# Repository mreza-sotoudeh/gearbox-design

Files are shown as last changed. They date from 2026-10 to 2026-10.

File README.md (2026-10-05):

# Gearbox Design
<p align="center">
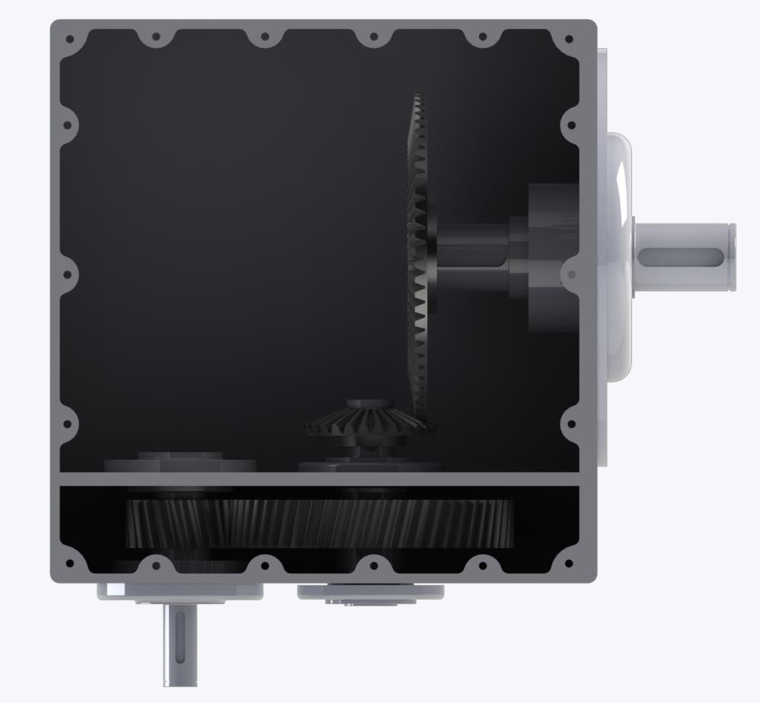
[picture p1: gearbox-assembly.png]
Cutaway view of the gearbox assembly
  
</p>

Mechanical design and analysis of a two-stage reduction gearbox, developed as an academic machine-design project.

The project covers the complete design process from power transmission requirements and gear calculations to shaft design, bearing selection, housing design, and the final SolidWorks assembly.

## Project Overview

The gearbox receives power from an 11 kW motor through a V-belt drive. Speed reduction is achieved using a helical gear stage followed by a bevel gear stage.

| Parameter | Value |
| --- | ---: |
| Motor power | 11 kW |
| Motor speed | 1440 rpm |
| Gearbox input speed  | 500 rpm |
| Helical-stage ratio  | 2.95 |
| Bevel-stage ratio | 2.45 |
| Total internal ratio | Approximately 7.23 |

## Design Scope

* Helical and bevel gear design
* Shaft design and strength calculations
* Bearing selection and arrangement
* Gearbox housing and cover design
* Fastener, seal, and retaining-element selection
* Complete 3D assembly and engineering drawings

## Repository Contents

* [`solidworks/`](solidworks/) — SolidWorks assemblies, parts, drawings, and exported previews
* [`English project report`](docs/gearbox-design-report-en.pdf) — Concise English design report
* [`Persian project report`](docs/gearbox-design-report-fa.pdf) — Complete original project report

## Tools

* SolidWorks
* Engineering design calculations
* Machine-element design methods

## Authors

* Ali Sakhaei
* Mohammadreza Sotoudeh

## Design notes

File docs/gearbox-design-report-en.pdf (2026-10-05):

MACHINE DESIGN II | PORTFOLIO EDITION

# Two-Stage Gearbox Design

### Mechanical analysis, component selection and SolidWorks assembly

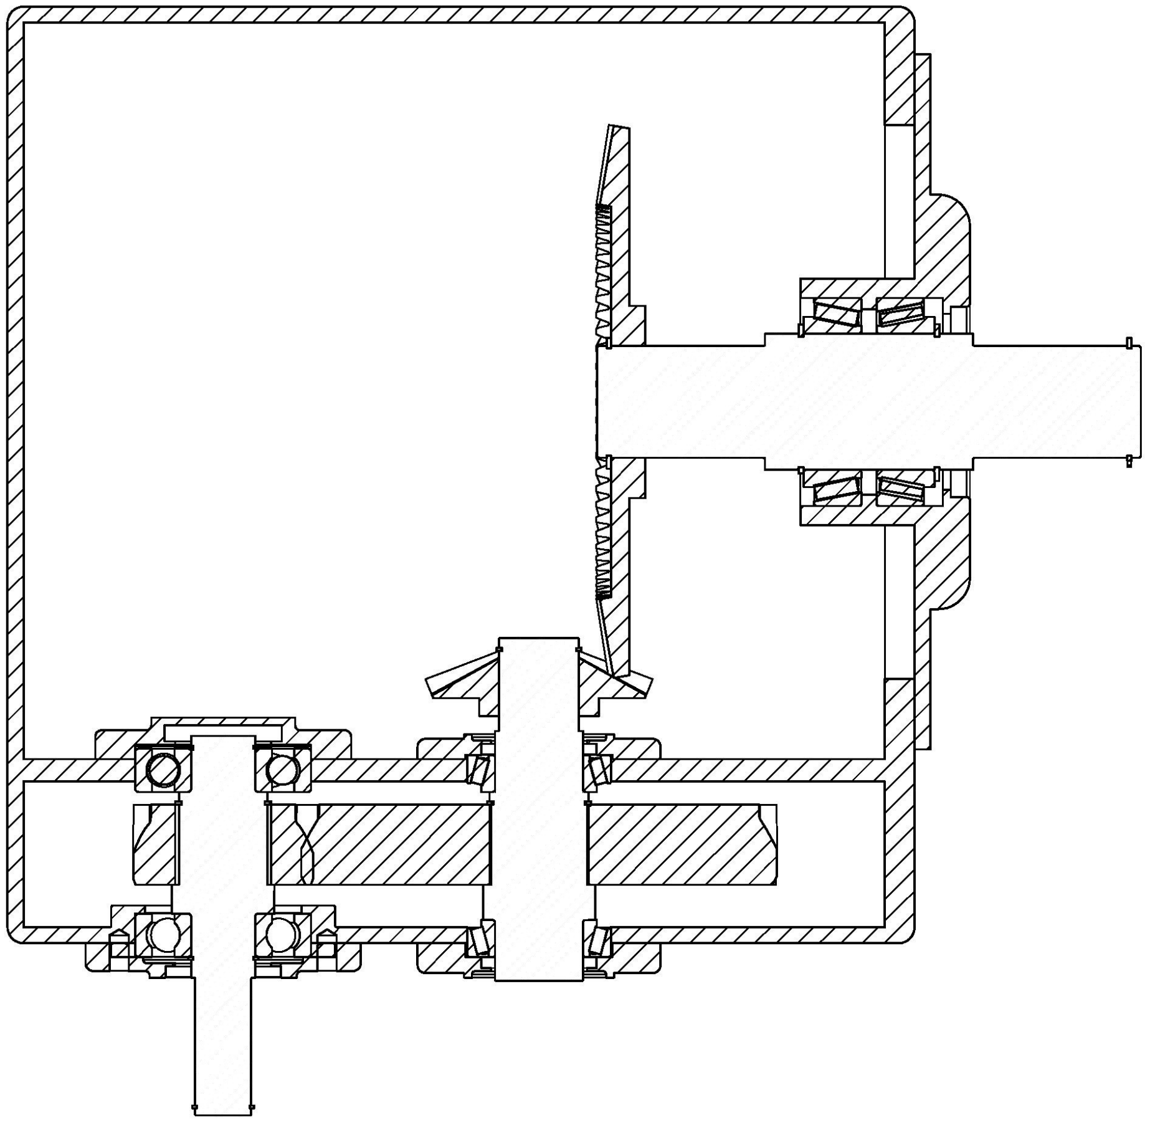
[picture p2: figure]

### Ali Sakhaei | Mohammadreza Sotude

Sharif University of Technology | Academic team project | 2025-2026

github.com/alisakhaei/gearbox-design

01 / PROJECT OVERVIEW

# Design Basis and Transmission Layout

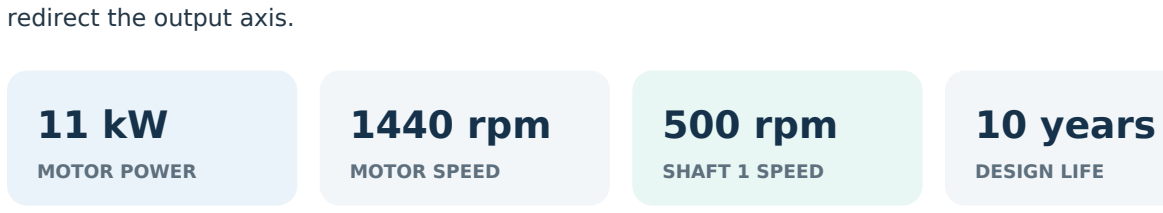
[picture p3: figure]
redirect the output axis.; MOTOR POWER; 1440 rpm; MOTOR SPEED; 500 rpm; SHAFT 1 SPEED; 10 years; DESIGN LIFE
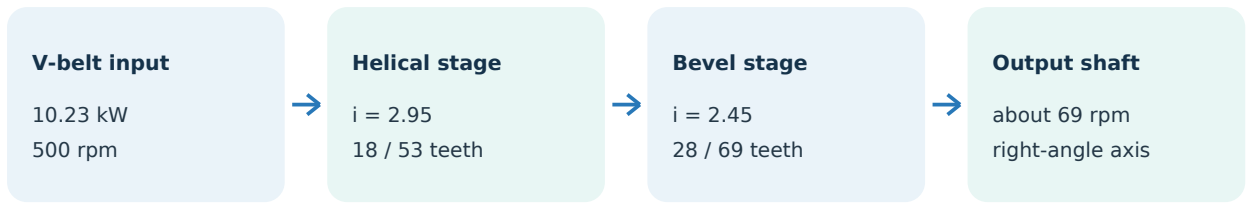
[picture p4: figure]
V-belt input; 500 rpm; Helical stage; 18 / 53 teeth; Bevel stage; 28 / 69 teeth; Output shaft; about 69 rpm; right-angle axis

GEARBOX DESIGN | ACADEMIC PROJECT | 2

The project develops a complete two-stage gearbox from analytical sizing to a detailed SolidWorks assembly. The transmission uses a helical parallel-axis stage followed by a straight bevel stage to

POWER FLOW

CORE ASSUMPTIONS AND CHOICES

Effective power after the V-belt is 10.23 kW, giving 195.4 N m torque at the first gearbox shaft.

Gear material: quenched and tempered 34CrMo4, with design checks based on bending and contact stress.

Shaft material: CK45 steel; stepped diameters were sized under combined bending and torsion.

A 99% reliability target and practical standard sizes were used where specified in the original calculations.

CALCULATION FRAMEWORK

Torque from power and speed | Stage ratio
Tangential tooth load | Basic bearing life

02 / GEAR DESIGN

# Helical and Bevel Gear Stages

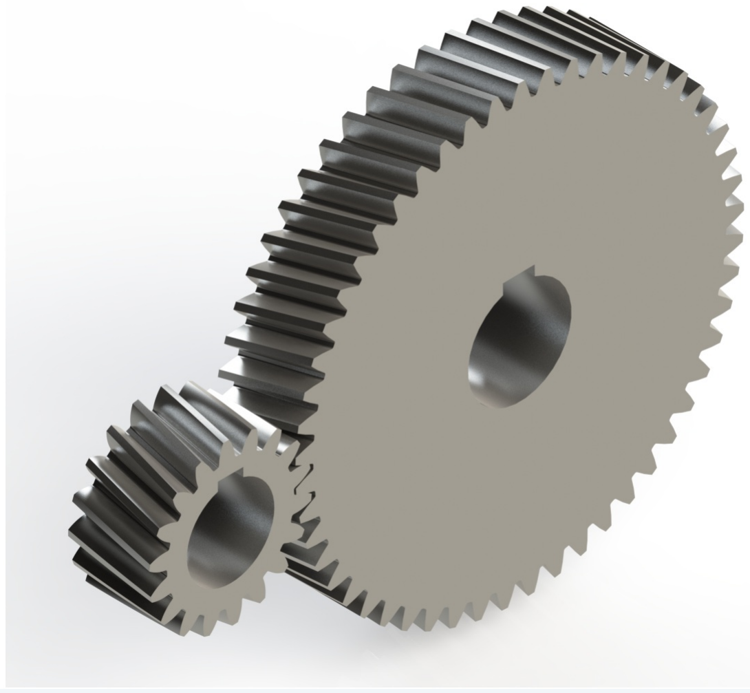
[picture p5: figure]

GEARBOX DESIGN | ACADEMIC PROJECT | 3

STAGE 1 - SELECTED HELICAL PAIR

Parameter | Selected value
Speed ratio | 2.95 : 1
Tooth count | 18 / 53
Normal module | 5 mm
Helix angle | 13 deg
Pitch diameters | 92.4 / 272 mm
Face width | about 51 mm

Both spur and helical alternatives were evaluated. The helical pair was carried forward for the detailed gearbox layout. The selected geometry is based on standard module sizing after bending and surface durability checks.

STAGE 2 - STRAIGHT BEVEL PAIR

Parameter | Selected value
Speed ratio | 2.45 : 1
Tooth count | 28 / 69
Module | 6 mm
Pitch diameters | 168 / 414 mm
Face width | 58 mm
Pitch angles | 22.1 / 67.9 deg

Verified operating point

Power entering stage: 9.92 kW

Shaft speed: about 170 rpm

Transmitted torque: 557.2 N m

# Shaft Design and Bearing Selection

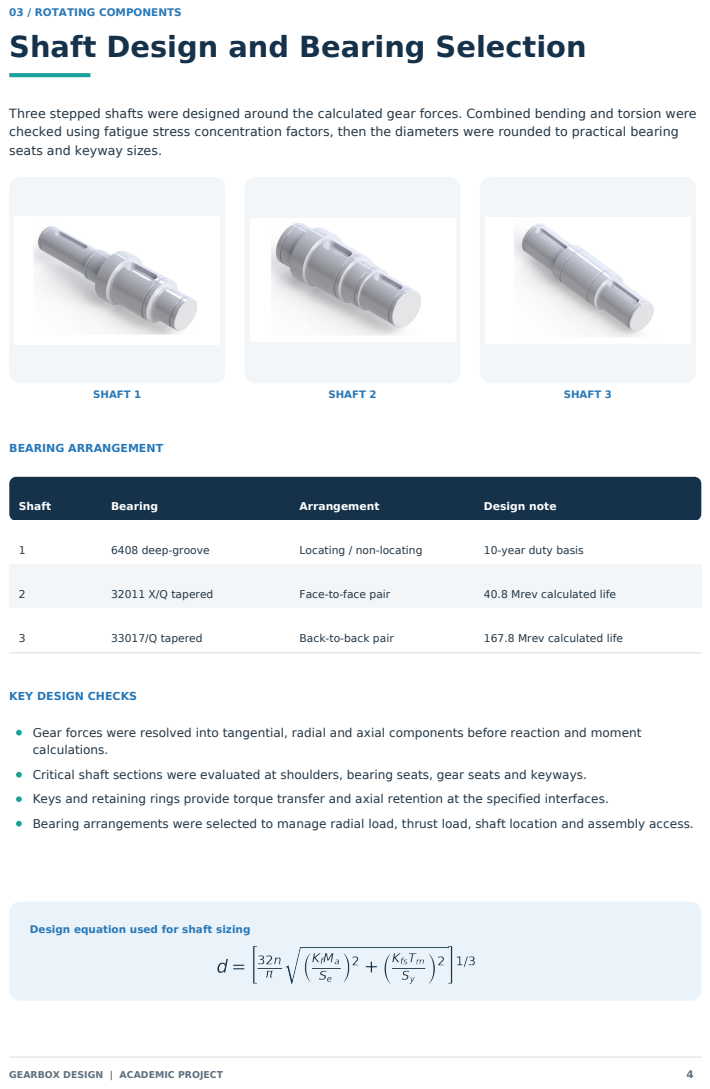
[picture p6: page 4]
03 / ROTATING COMPONENTS; GEARBOX DESIGN | ACADEMIC PROJECT; SHAFT 1; SHAFT 2; SHAFT 3; BEARING ARRANGEMENT; Shaft; Bearing; Arrangement; Design note; 6408 deep-groove; Locating / non-locating; 10-year duty basis; 32011 X/Q tapered; Face-to-face pair; 40.8 Mrev calculated life; 33017/Q tapered; Back-to-back pair; 167.8 Mrev calculated life

Three stepped shafts were designed around the calculated gear forces. Combined bending and torsion were
checked using fatigue stress concentration factors, then the diameters were rounded to practical bearing
seats and keyway sizes.

KEY DESIGN CHECKS

Gear forces were resolved into tangential, radial and axial components before reaction and moment
calculations.

Critical shaft sections were evaluated at shoulders, bearing seats, gear seats and keyways.

Keys and retaining rings provide torque transfer and axial retention at the specified interfaces.

Bearing arrangements were selected to manage radial load, thrust load, shaft location and assembly access.

Design equation used for shaft sizing

04 / ENCLOSURE

# Housing, Fasteners and Sealing

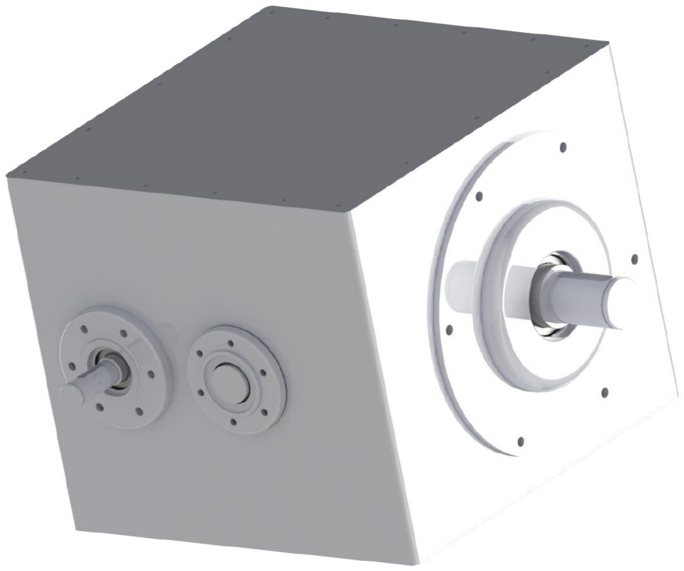
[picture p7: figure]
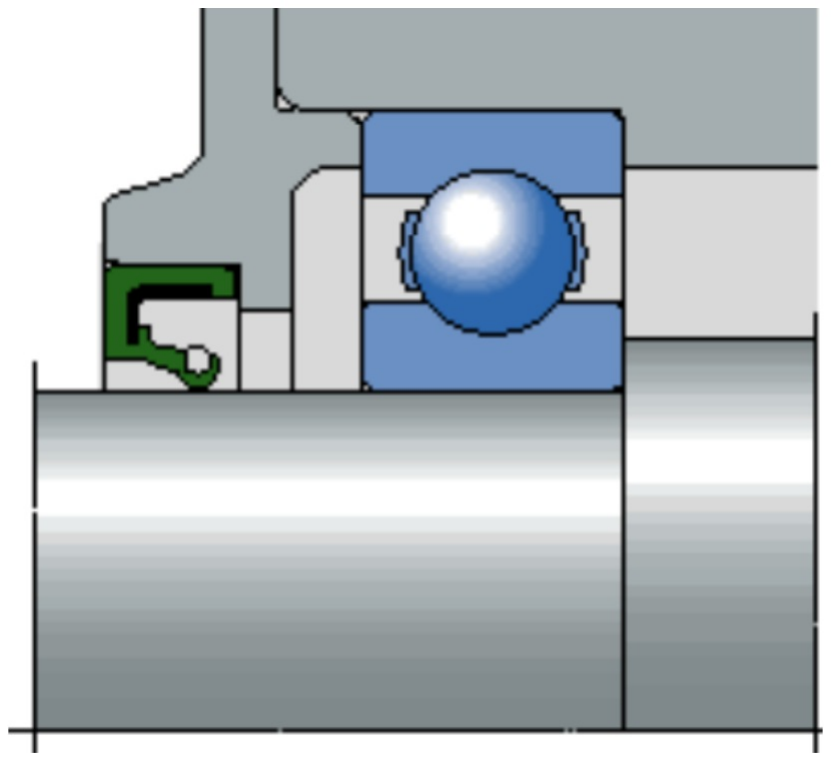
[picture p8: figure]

GEARBOX DESIGN | ACADEMIC PROJECT | 5

HOUSING DESIGN

Steel plate construction was checked against bearing reaction loads.

Calculated local minima were increased to practical 10-12 mm plate selections.

Removable covers, bearing flanges and a dedicated output-shaft housing support assembly and service access.

Fastener sizes include M10, M12, M14 and M16 selections across the casing and support interfaces.

RADIAL SHAFT SEALING

Location | Selected seal
Behind B1 | Type A 40-72-7
Behind B3 | Type A 55-80-8
Behind B6 | Type A 85-120-12

Type A radial lip seals were selected to limit lubricant leakage and contaminant ingress. Seal seats were integrated into the bearing flanges and the third-shaft housing.

Manufacturing intent

Use standard plate thicknesses, standard rolling bearings and catalog seals to keep the design serviceable.

05 / CAD INTEGRATION

# Assembly Architecture and Deliverables

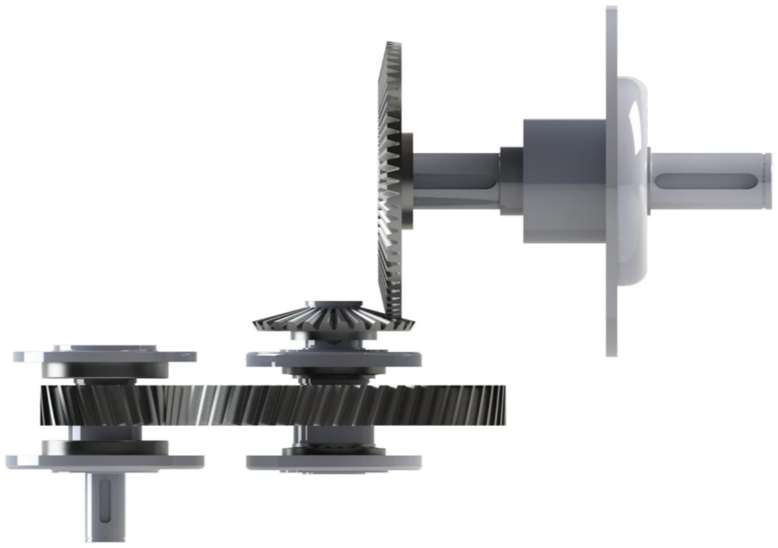
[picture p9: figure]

GEARBOX DESIGN | ACADEMIC PROJECT | 6

ASSEMBLY LOGIC

Shaft 1 carries the helical pinion and is supported by the locating/non-locating ball-bearing pair.

Shaft 2 carries the helical gear and bevel pinion, with a face-to-face tapered-roller arrangement.

Shaft 3 carries the bevel gear and output element, supported by a back-to-back tapered-roller pair.

REPOSITORY-READY DELIVERABLES

Deliverable | Contents
SolidWorks source files | Parts, subassemblies, main assembly and drawings
Engineering drawings | Gears, shafts, flanges, housing and sectional views
Persian calculation report | Complete academic report with detailed calculations
English portfolio report | Concise design summary and selected results

06 / SUMMARY

# Engineering Outcomes

GEARBOX DESIGN | ACADEMIC PROJECT | 7

FINAL CONFIGURATION

Item | Final selection
Architecture | Two-stage, three-shaft, right-angle gearbox
First stage | Helical pair, i = 2.95, module 5 mm
Second stage | Straight bevel pair, i = 2.45, module 6 mm
Internal reduction | Approximately 7.23 : 1
Gear material | 34CrMo4, quenched and tempered
Shaft material | CK45 steel
CAD platform | SolidWorks

WHAT THE PROJECT DEMONSTRATES

Translation of power, speed and service-life requirements into a complete transmission layout.

Gear sizing with bending and surface durability checks, including comparison of spur and helical alternatives.

Integrated design of shafts, bearings, keys, retaining rings, seals, housing plates and fasteners.

CAD assembly planning supported by manufacturing drawings, an exploded view and a bill of materials.

REPORT SCOPE

This English edition is a concise portfolio summary based on the complete Persian calculation report. It preserves the selected dimensions and component choices while omitting student numbers and personal contact details.

PROJECT CREDIT

Academic team project by Ali Sakhaei and Mohammadreza Sotude.

Repository: github.com/alisakhaei/gearbox-design

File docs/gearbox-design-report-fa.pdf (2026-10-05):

دانشگاه صنعتي شريف
دانشكده مهندسي مكانیک

گزارش درس طراحي اجزاء ماشین 2

عنوان

# گزارش پروژه طراحي چرخدندهها و گیربكس

نگارش

## محمدرضا ستوده 402107271 علي سخايي 402107282

دکتر دورعلي

دی 1404

چكيده أ

## گزارش پروژه طراحي چرخدندهها و گیربكس

چكیده

این پروژه به طراحی جامع و تحليل فنی-اقتصاای یايماتن اات اد قد)گ ربيربكبا با تزربر بر بهينهیاز چرخدادهها پيشاای و مخروطی میپریازی. فرایند طراحی ی) یو فاز اصلی تدوین شده ایت؛ ی) فاز اخمت، م ایمها تحليلی ميان چرخدادهها یایه و هليكاد از منظر ااتخاب موای، ظرفيت تحزل باا) و هریناههاا یااااخات صاااو)گ برفات تاا بهيناهترین بریناه ااتخااب و طراحی اهاایی بریی. فااز یو باه طراحی یقيق هندیای و ایات امتی چرخدادهها مخروطی یاایه اختصاای یافته ایات. ی) تزامی مراحل، اصود هنیاز با یيمتن یاتاقانبند و چيدمان شافتها از پيش طراحی شده، مالک عزل قرا) برفته ایات. از وییبیها با)ز این پروژه، ایات الد ی) تصازينبير جهت تعيين ضارایا اطزينان، )و ها یااخت و متریاد بر ایااا ایاتاادا)یها مهندیای ایات. خروجی اهایی شاامل یفترچه محایالاگ بامل، ا شاهها اجرایی، ليمات موای (BOM (و برآو)ی یقيق هرینهها توليد میباشاد به ی) بخش تكزيلی، با بازاگر بر محایلاگ شافت و پویته، به یک طرح جامع از بل یيمتن بيربكب منتهی شده ایت.

فهریت مطالا ب

صفحه | فهرست مطالب

### 1 مقدمه1 |

### 2 تشريح مسئله 2 |

2.1 محایلاگ م دماتی مزان پيچشی3 |

### 3 چرخدنده ی ساده 4 |

3.1 )اد)بير چرخداده یایه | 6

### 4 چرخدنده ی هلیكال 7 |

4.1 )اد)بير چرخداده هليكاد 9 |

### 5 چرخدنده ی هلیكال يا ساده؟10 |

### 6 چرخدنده ی مخروطي ساده 11 |

6.1 )اد)بير چرخداده مخروطی یایه 14 |

### 7 شافت | 1 15

7.1 محایلاگ اوليه شافت 1 15 |
7.2 محایله قطر شافت 1 | 16
7.3 محایله خا) شافت 17 | 1
7.4 ااتخاب بيرینگ برا شافت 1 18 |
7.5 ازا بلی شافت 1 20 |

### 8 شافت | 2 21

8.1 محایلاگ اوليه شافت 2 21 |
8.2 محایله قطر شافت 2 22 |
8.3 محایله خا) شافت 22 | 2
8.4 ااتخاب بيرینگ برا شافت 2 23 |
8.5 ازا بلی شافت 2 24 |

### 9 شافت 25 | 3

9.1 محایلاگ اوليه شافت 3 و قطر25 |
9.2 محایلاگ خا) شافت | 3 26
9.3 ااتخاب بيرینگ برا شافت 3 | 26

فهریت مطالا ب

9.4 ازا بلی شافت 3 27 |
10.1 محایله ضخامت و)ق و Housing28 |
10.2 محایله پيچ ها پویته 29 |
10.3 )اد)بير بيربكب 30 |
10.3.1 خا)ج بيربكب 30 |
10.3.2 یاخل بيربكب 31 |
10.3.3 یاخل بيربكب ربدون پویتها32 |

### 11 نشتبندی 33 |

12.1چرخداده یایهPinion 34 |
12.2چرخداده یایه Gear 35 |
12.4چرخداده هليكاد Gear 37 |
12.5چرخداده مخروطی Pinion 38 |
12.6 چرخداده مخروطی Gear39 |
12.7شافت 1 40 |
41 | Flange 1 (For B1)12.8
42 | Flange 2 (For B2) 12.9
12.10 شافت 2 43 |
44 | Flanges 3&4 (For B3 & B4) 12.11
12.12 شافت 3 45 |
12.14 پویته بي ربكب (Case(47 |
12.15 ی) پویته ب يربكب رDoor Caseا 48 |
12.16 ا شه م طع بيربكب 49 |
50 | Exploded View 12.17
51 | Bill of Material 12.18

### 13 مونتاژ 52 |

فهریت مطالا ب

13.1 احوه مواتاژ 52 |
13.2 تثليت محو) و یو)اای قطعاگ53 |

فصل اود: م دمه 1

## 1 مقدمه

یايماتنها اات اد قد)گ و ی) )أا آنها بيربكبها، ا شای حياتی ی) ماشاينآالگ صانعتی ایفا میبنند . طراحی یک بيربكب با)آمد، تنها به محایالاگ ترو)یک محدوی ازیشاوی، بلكه مماتلر اتخا تصازيزاگ مهندیای ی) زمينه ااتخاب موای، )و ها یااخت و بهينهیااز اقتصاای ایات. ی) این پروژه، هدف اصااالی طراحی اجرا یادهبناد یاک یااايماااتن اات ااد قد)گ با تكيه بر آموختهها پيشاااين و ایتاادا)یها طراحی اجرا ایت. )واد طراحی ی) این برا) با بر)یاای تطلي ی ميان چرخدادهها پيشاااای ریااایها و هليكاد آغاز میبریی. از آاجاایی باه ااتخااب بين این یو اوع چرخادااده ممااات يزااً بر باازیهی، ميران ا)تعااشااااگ و هرینهها ماشاينبا) تأثيربذا) ایات، ی) فاز اخمات پروژه، این یو )اهكا) از منظر متریاد و هرینهها تولياد مو)ی وابااو قرا) برفتاهاااد. ی) بخش یو ، طراحی چرخاداادههاا مخروطی برا اات ااد توان بين محو)ها مت اطع مد اظر قرا) برفته ایت. این برا) عالوه بر ا)ائه محایالاگ یقيق، به جنلهها اجرایی از جزله ا شاهها یااخت و برآو)ی ليمت موای رBOMا اير میپریازی تا یک پكيج بامل مهندی ی از ایده تا توليد )ا ا)ائه یهد .

فصل یو : تشریح ممرله 2

## 2 تشريح مسئله

هزااطو) به ی) بالا توضايح یایه شاد، ی) این پروژه ميخواهين چرخداده ها بيربكب پروژه 2
)ا طراحی بنين. برا مرحله اود )اه حلها یااایه و هليكاد )ا از اظر موای و هرینه یاااخت م ایمااه و چرخداده منایاا )ا ااتخاب و بطو) بامل طراحی ازایيد. برا مرحله یو چرخداده ها مخروطی یاایه اياز خواهد بوی به ی) اینجا هن )اه حل )ا تا طراحی بامل پيش بلرید . شاااكل اهایی یاده ها باید با ااچه ی) پروژه 2 از اظر بيرینگ بند و اصااا طراحی ازویید تا حد امكان هزماااز یاشااته باشااد. بماايا) خوشاحالن به ی) این پروژه با توجه به آموخته هایتان ميتواايد از اظر ضاریا اطزينان، ااتخاب موای، )و یاخت و )و اصا تزامی تصزيزها )ا خویتان بگيرید .خروجی این پروژه محایلاگ و ا شه ها یاخت و هرینه یاخت چرخداده ها ميلاشد . با توچه به اینكه ی) پروژه ها 2 و 3 محایلاگ شافت ها و بيرینگ ها و بداه و اشات بند ها )ا ااجا یایه اید، با توجه به ارییكی ابعای با فرضاياگ اوليه ی) صاو)تيكه تزایل به ا)ایه طرح بامل بيربكب یاشااته باشاايد، با توجه به ابعای یاده ها طراحی شااده، ميتواايد محایاالاگ مربوطه )ا بطو) خالصاااه با اقتلاا از پروژه ،2 تكرا) ازویه و طرح بامل بيربكب و ا شاااه ها اجرایی قطعااگ ان، ليمااات موای و قطعااگ و هریناه تولياد اارا اير تكزيال بریه و تحویال یهياد. ااجاا این بخش تاا 30٪ ازره اضافی برا بروه شزا خواهد یاشت.

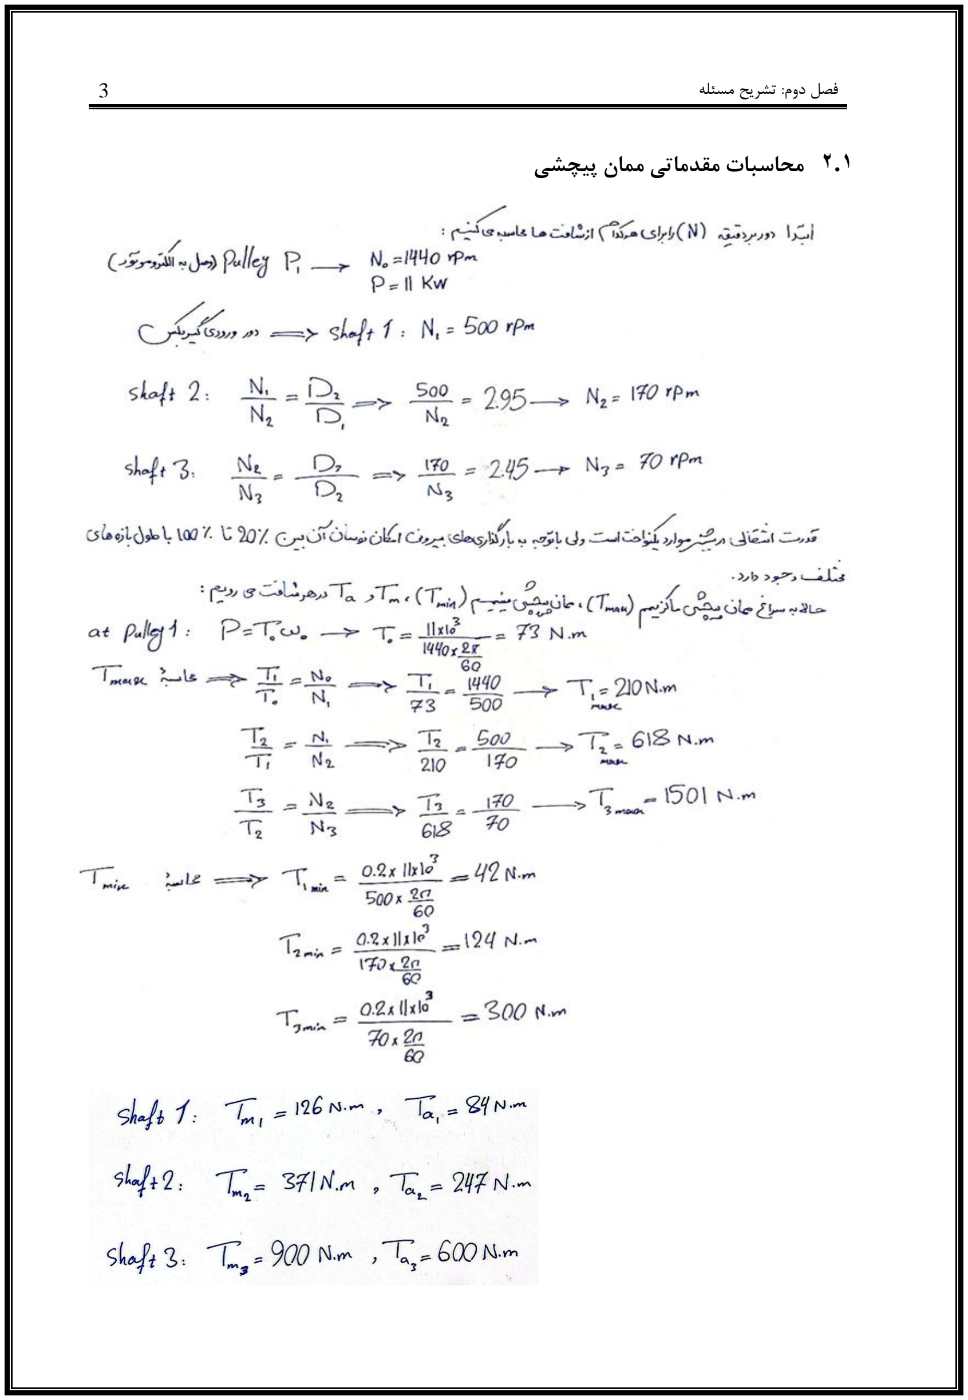
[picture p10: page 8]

فصل یو : تشریح ممرله 3

محاسبات مقدماتي ممان پیچشي

2

1

فصل یو : چرخداده یایه 4

## چرخدندهی ساده

3

فصل یو : چرخداده یایه 5

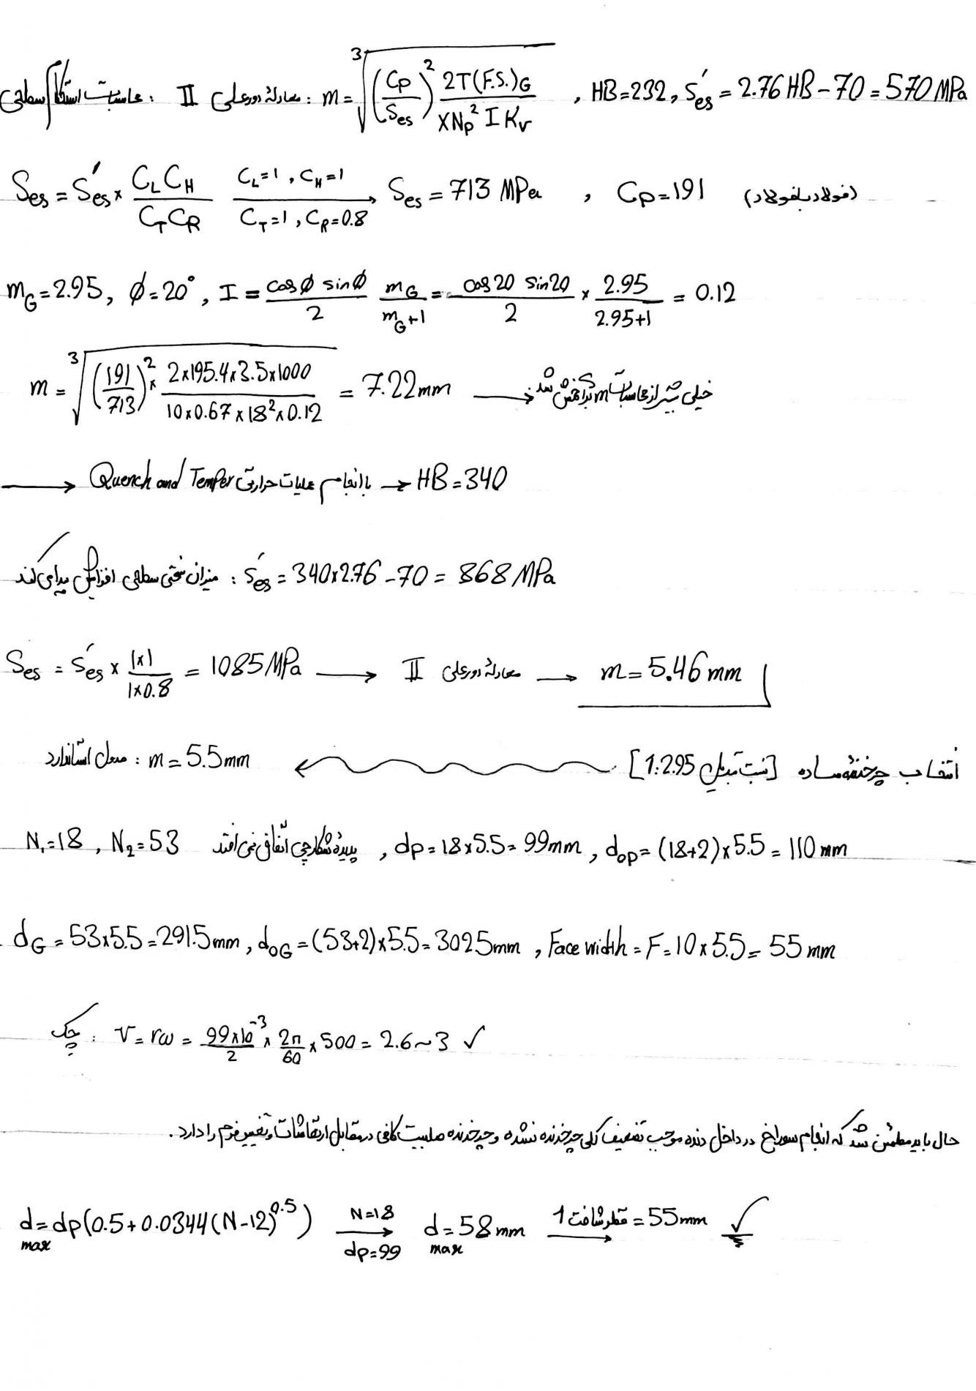
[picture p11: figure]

فصل یو : چرخداده یایه 6

رندرگیری چرخدنده ی ساده

3

1

فصل چها) : چرخداده هليكاد 7

## چرخدندهی هلیكال

4

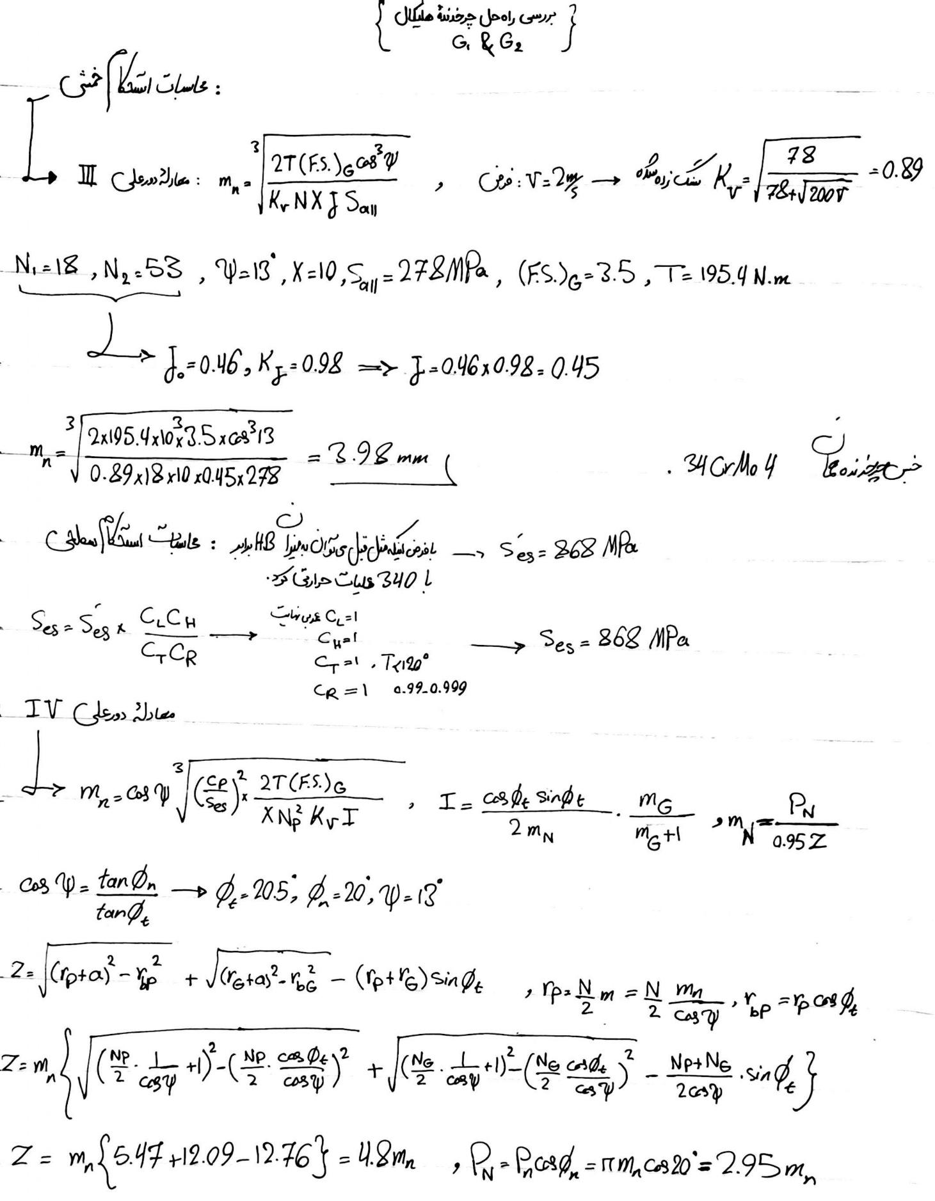
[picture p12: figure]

فصل چها) : چرخداده هليكاد 8

فصل چها) : چرخداده هليكاد 9

رندرگیری چرخدنده ی هلیكال

4

1

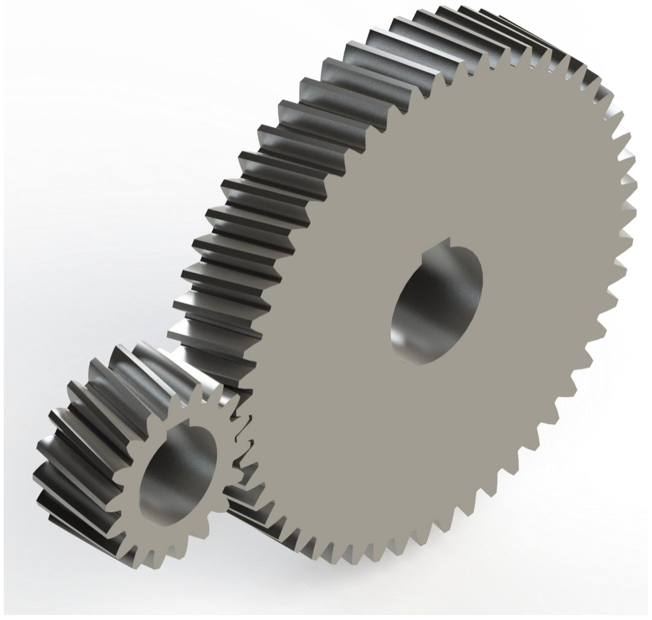
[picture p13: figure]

فصل پنجن: ااتخاب بين یو اوع چرخداده 10

## 5 چرخدندهی هلیكال يا ساده؟

هر یو اوع چرخادااده باه ییااات آماده، وییبیهاا الز برا بيربكب )ا یا)ااد. از لحااظ هریناه یااخت و مایه، ااتخاب چرخداده هليكاد م رون به صارفهتر ایات. به عالوه، چرخدادهها هليكاد به یليل قطر خا)جی بزترشاان امالت به چرخدادهها یاایه، فضاا بزتر )ا از بيربكب میبيراد. اللته یااخت چرخد اده هليكاد به یليل عزلياگ حرا)تی و یانگ زین یاختتر و بزی پرهرینه تر ایات؛ اما فوالی بزتر ی) آن ایتفایه شده ایت.

بنابراین از چرخداده اوع هليكاد ایتفایه میبنين.

فصل ششن: چرخداده مخروطی یایه 11

## 6 چرخدندهی مخروطي ساده

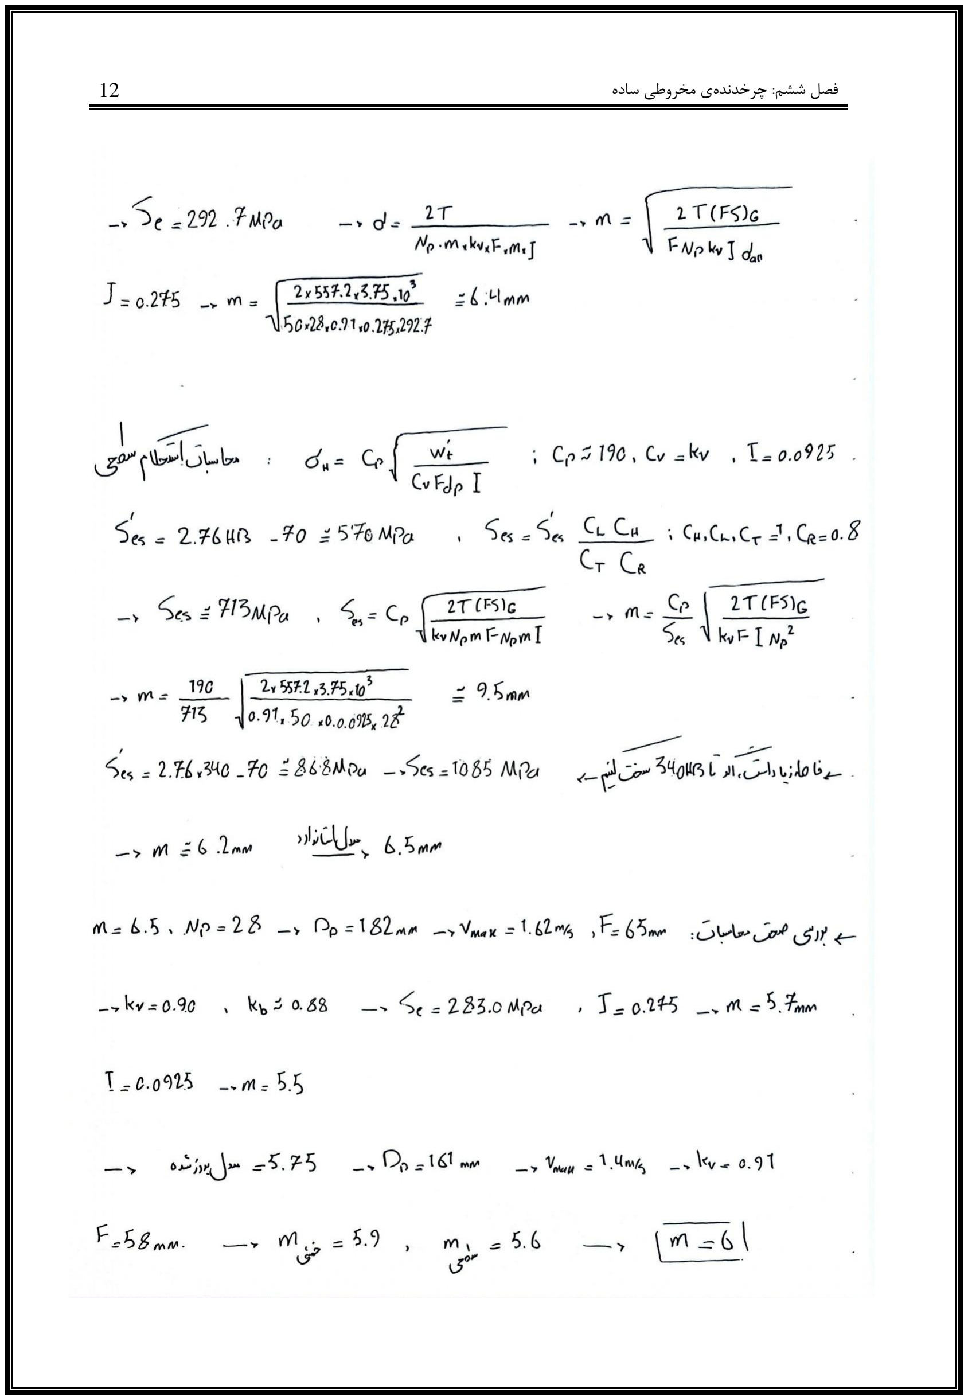
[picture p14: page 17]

فصل ششن: چرخداده مخروطی یایه 12

فصل ششن: چرخداده مخروطی یایه 13

فصل ششن: چرخداده مخروطی یایه 14

### 6.1 رندرگیری چرخدنده مخروطي ساده

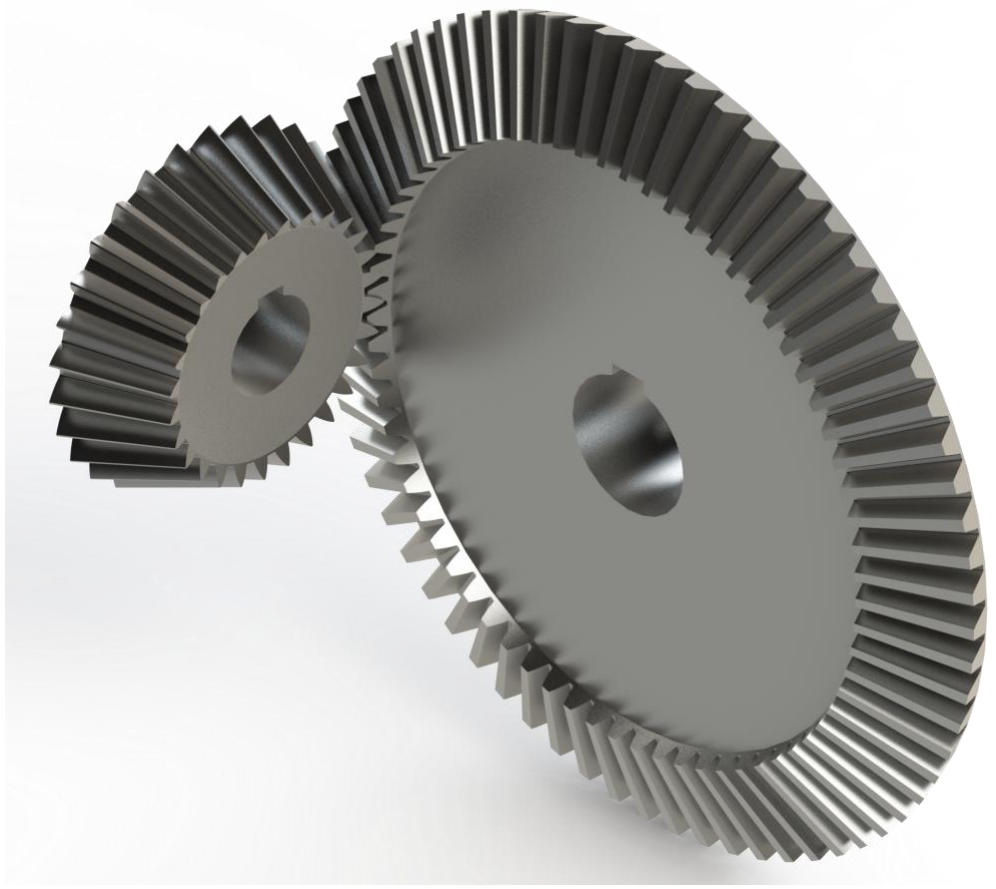
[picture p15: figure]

فصل هفتن: شافت 1 15

## 7 شافت 1

### 7.1 محاسبات اولیه شافت 1

این شااافت اماالت به پروژه قلل تغيير چنداای اكریه ایاات چون قطر با چرخداده هليكاد 1 ی) هزان حدوی برا پروژه 3 به ییت آمد.

16

فصل هفتن: شافت 1

محاسبه قطر شافت 1

7

2

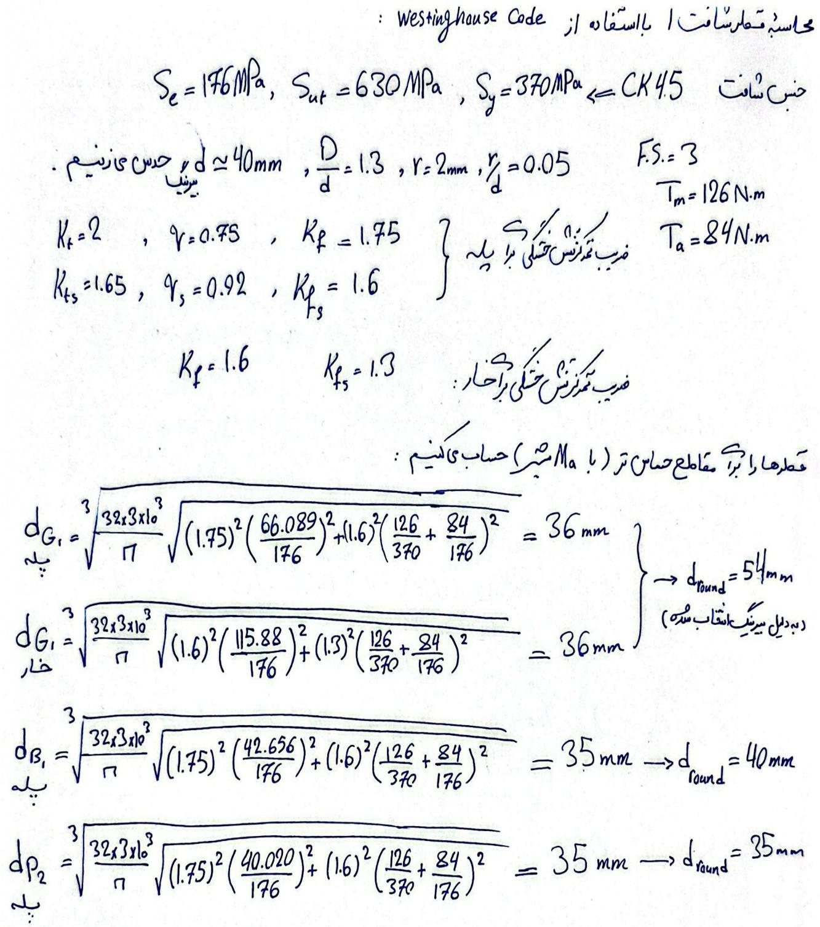
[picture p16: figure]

17

فصل هفتن: شافت 1

محاسبه خار شافت 1

7

3

18

فصل هفتن: شافت 1

انتخاب بیرينگ برای شافت 1

7

4

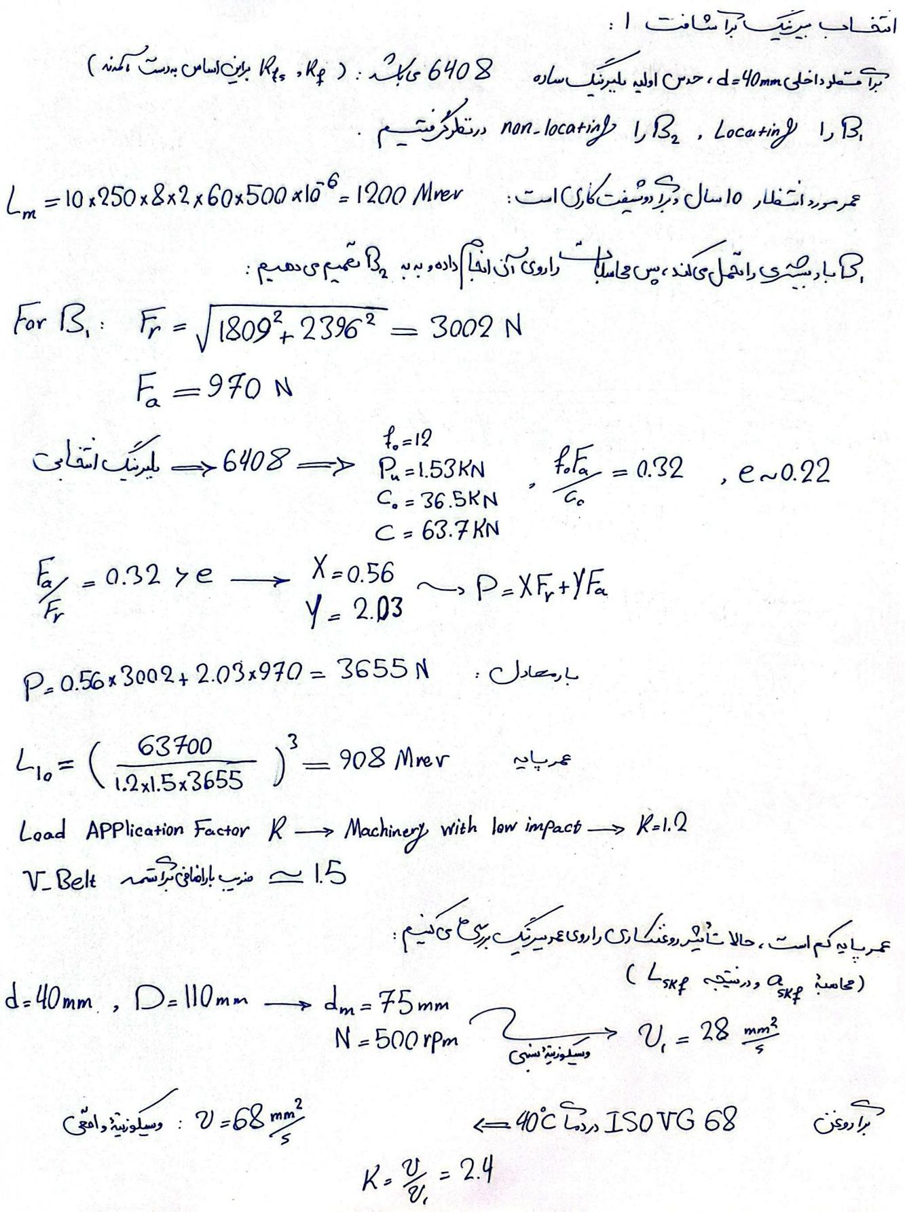
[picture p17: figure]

فصل هفتن: شافت 1 19

20

فصل هفتن: شافت 1

نمای کلي شافت 1

7

5

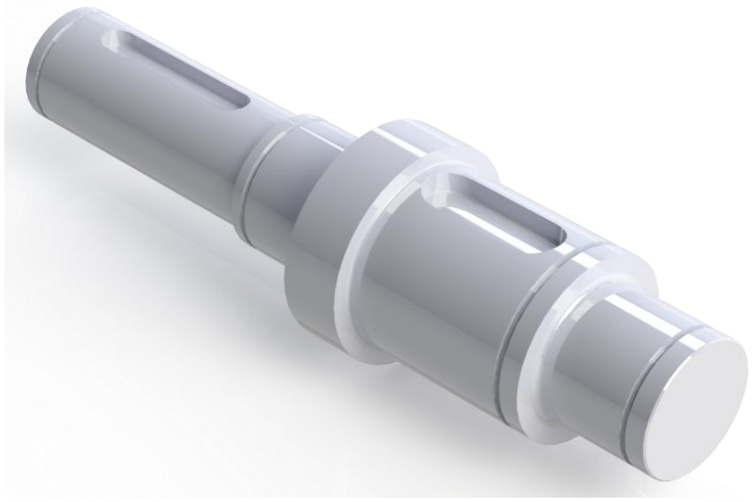
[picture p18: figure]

21

8 شافت 2 | فصل هشتن: شافت 2

محاسبات اولیه شافت 2

8

1

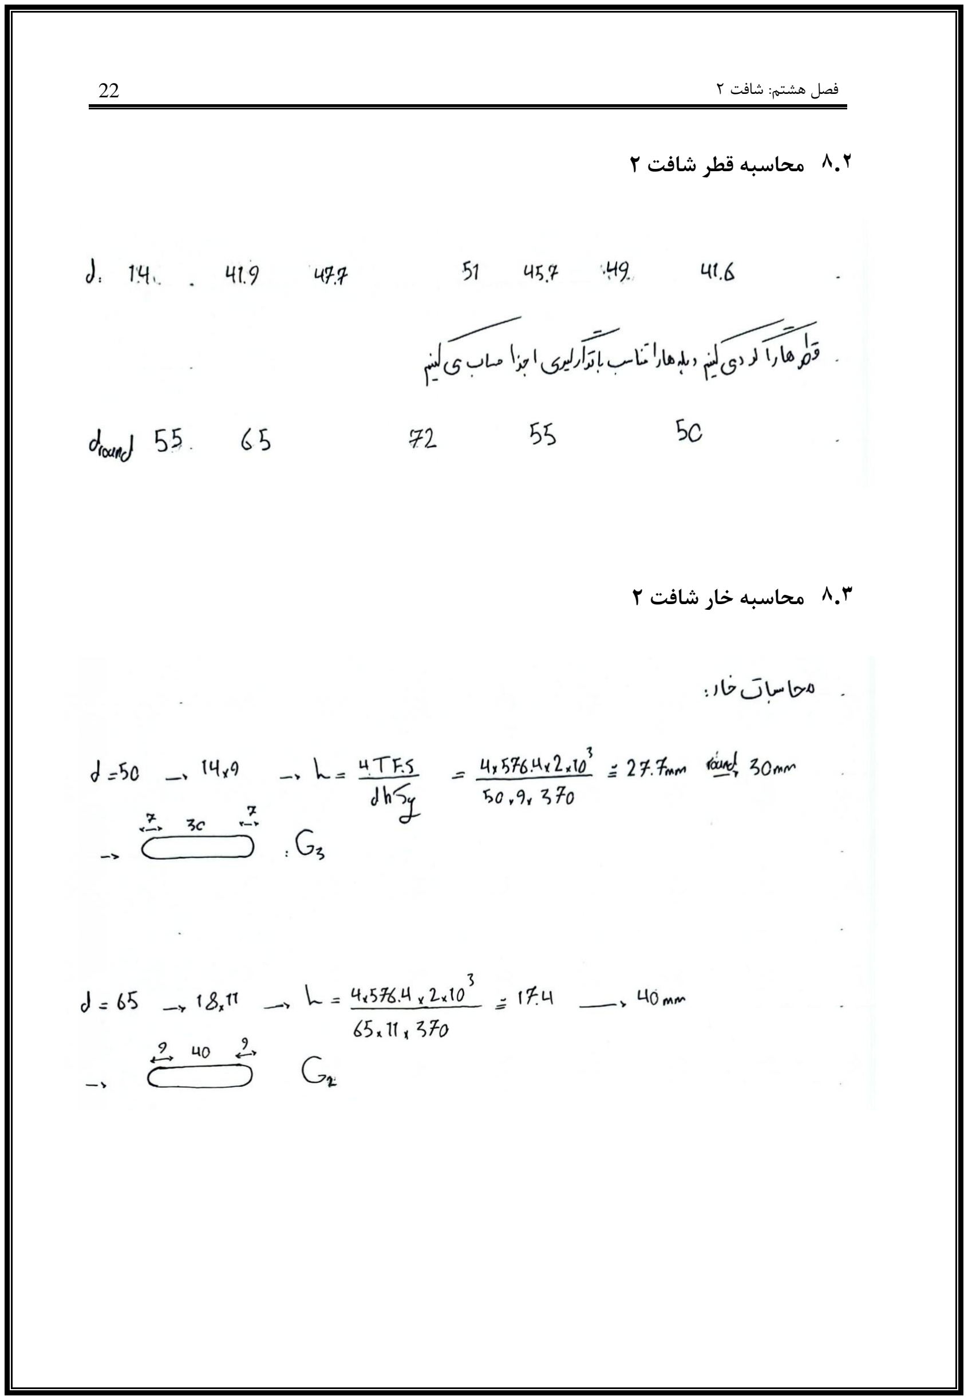
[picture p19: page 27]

فصل هشتن: شافت 2 22

### 8.2 محاسبه قطر شافت 2

### 8.3 محاسبه خار شافت 2

23

فصل هشتن: شافت 2

انتخاب بیرينگ برای شافت 2

8

4

24

فصل هشتن: شافت 2

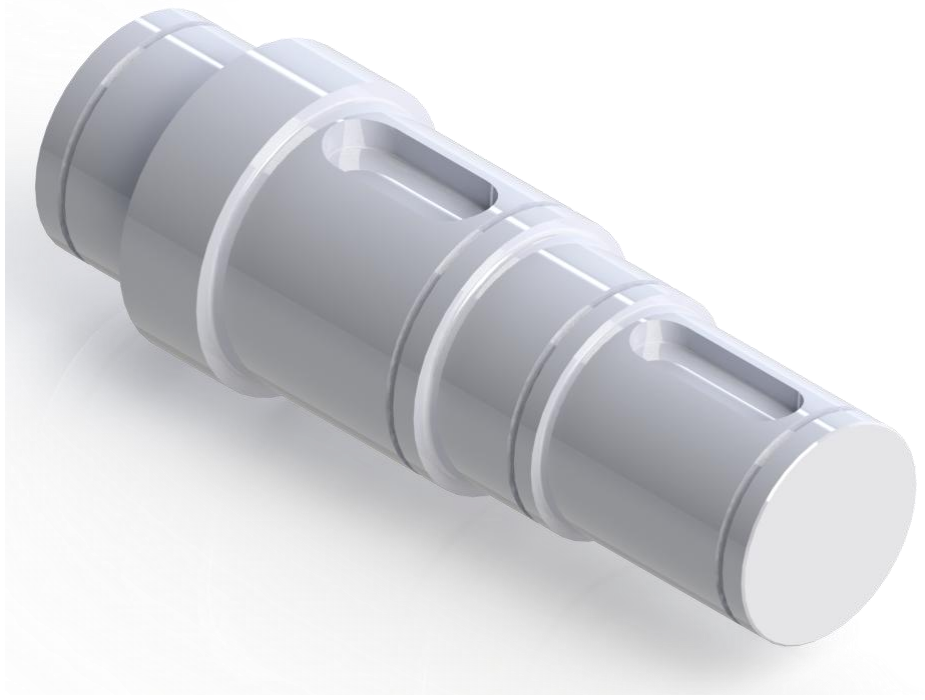
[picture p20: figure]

نمای کلي شافت 2

8

5

فصل اهن: شافت 3 25

## 9 شافت 3

### 9.1 محاسبات اولیه شافت 3 و قطر

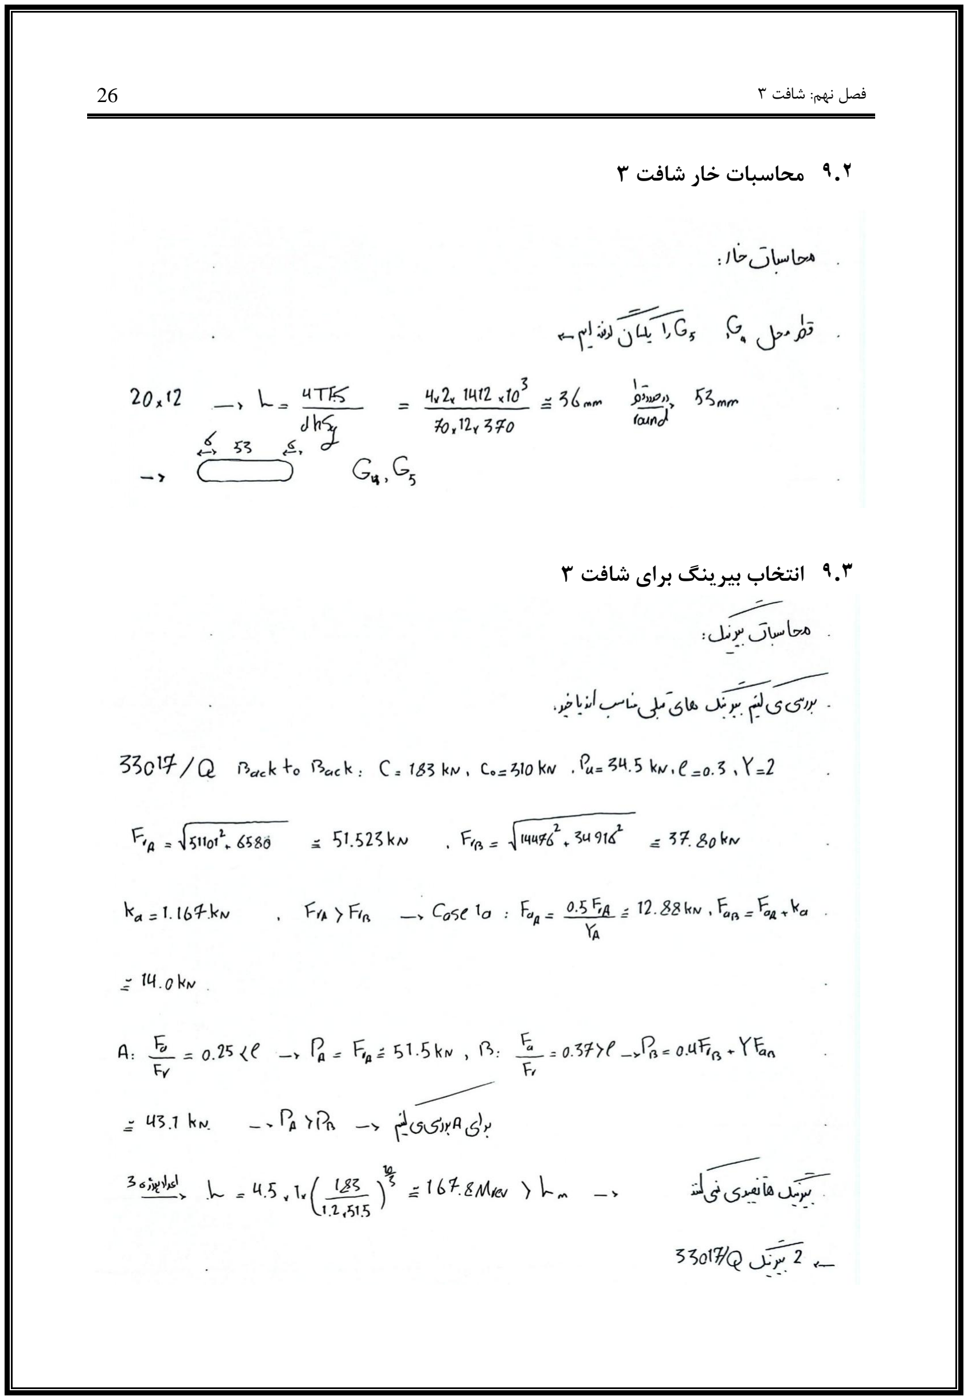
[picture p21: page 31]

فصل اهن: شافت 3 26

### 9.2 محاسبات خار شافت 3

### 9.3 انتخاب بیرينگ برای شافت 3

27

فصل اهن: شافت 3

نمای کلي شافت 3

9

4

فصل یهن: پویته بيربكب 28

## 10 پوستهی گیربكس

10.1محاسبه ضخامت ورق و Housing

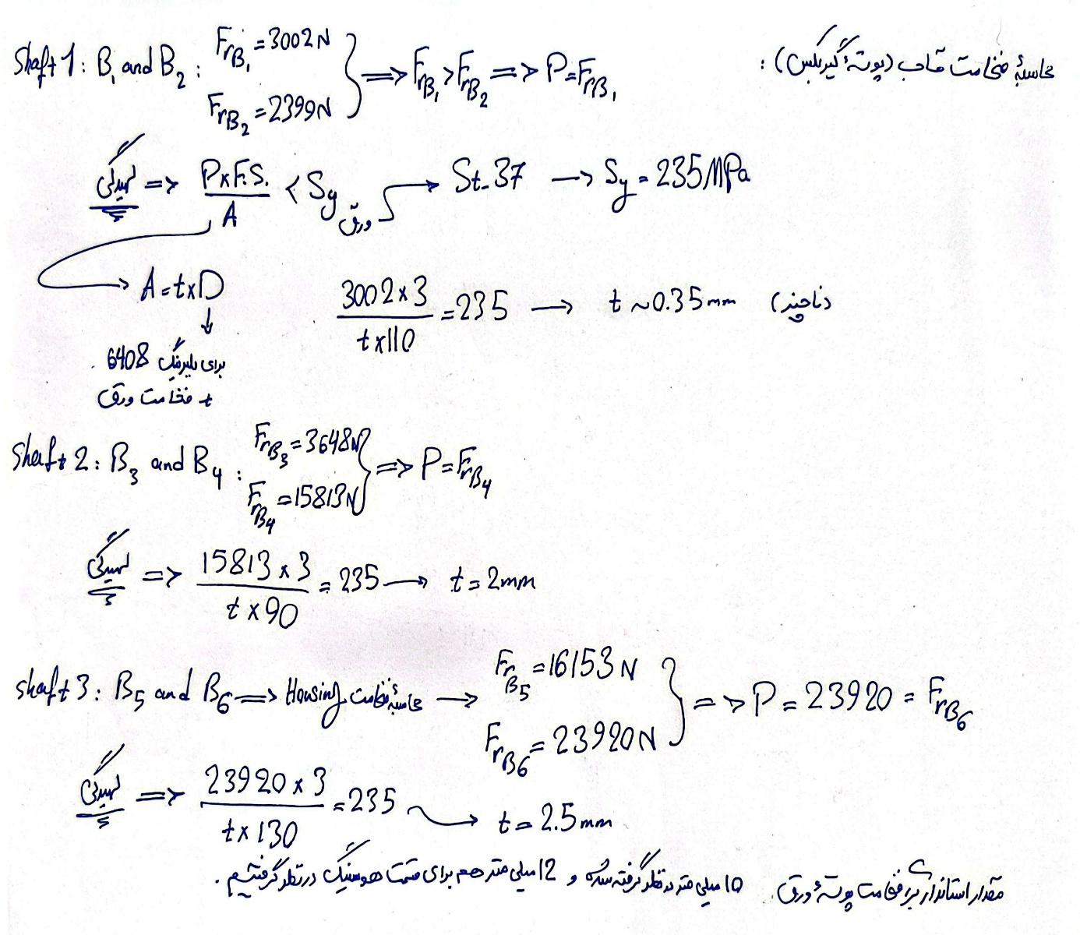
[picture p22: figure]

فصل یهن: پویته بيربكب 29

10محاسبه پیچ های پوسته

2

فصل یهن: پویته بيربكب 30

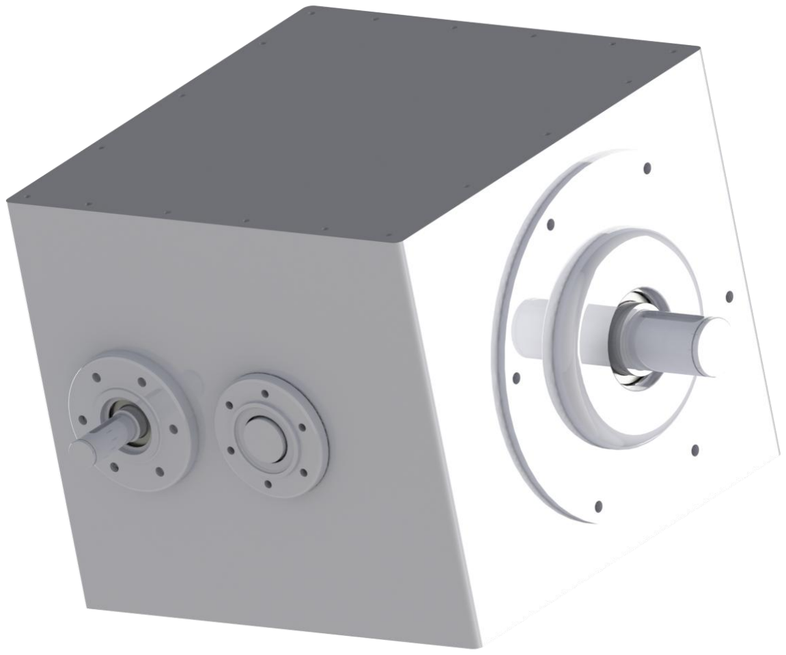
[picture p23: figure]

10رندرگیری گیربكس

3

10خارج گیربكس

3

1

فصل یهن: پویته بيربكب 31

10داخل گیربكس

3

2
توضااايحااگ: ااافیهاا 3G و 4G باایاد تاا پلاه مجاو)شاان امتدای پيدا بنند به ی) ار افرا) این با) برا چرخدادهها مخروطی یاااليدو)بب م دو) الوی.

فصل یهن: پویته بيربكب 32

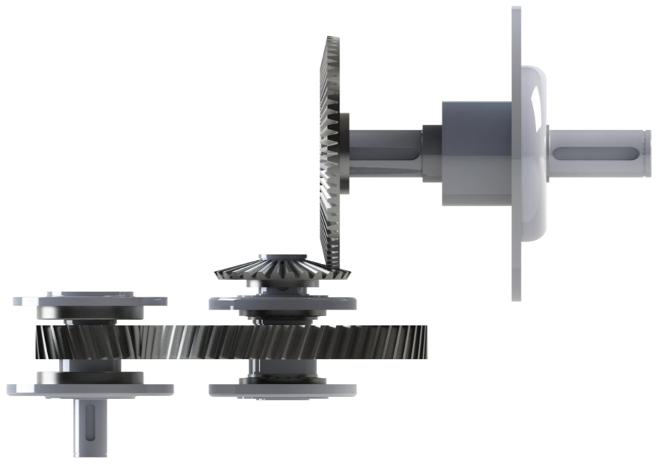
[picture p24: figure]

10داخل گیربكس )بدون پوسته(

3

3

فصل یازیهن: اشتبند 33

## 11 نشتبندی

ی) این بخش به ااتخاب اشاتبند برا جلوبير از و)وی بریوغلا) و خروج )وغن از بيربكب میپریازین. هزانطو) به مشاخ ایات، باید با توجه به قطر آن قمازت از شاافت به بيرینگها 1B، 3B و 5B قرا) یا)اد، بایاهازد منایاا ااتخاب شاوی. الز به بر ایات به برا بيربكب ها معزوال ی) صانعت از بایاه ازد اوع A ایتفایه میشوی. ااتخاب بایه ازد ها از قرا) زیر ایت:
- یک عدی بایه ازد 40-72-7 TypeA برا پشت 1B
- یک عدی بایه ازد 55-80-8 TypeA برا پشت 3B
- یک عدی بایه ازد 85-120-12 TypeA برا پشت 6B )و فلنج ها و هویاينگ شاافت ،3 محل اصاا برا این بایاه ازدها ی) اظربرفته شادهایات. احوه اصا هن باید به صو)گ زیر باشد:

فصل یوازیهن: ا شهها اجرا 34

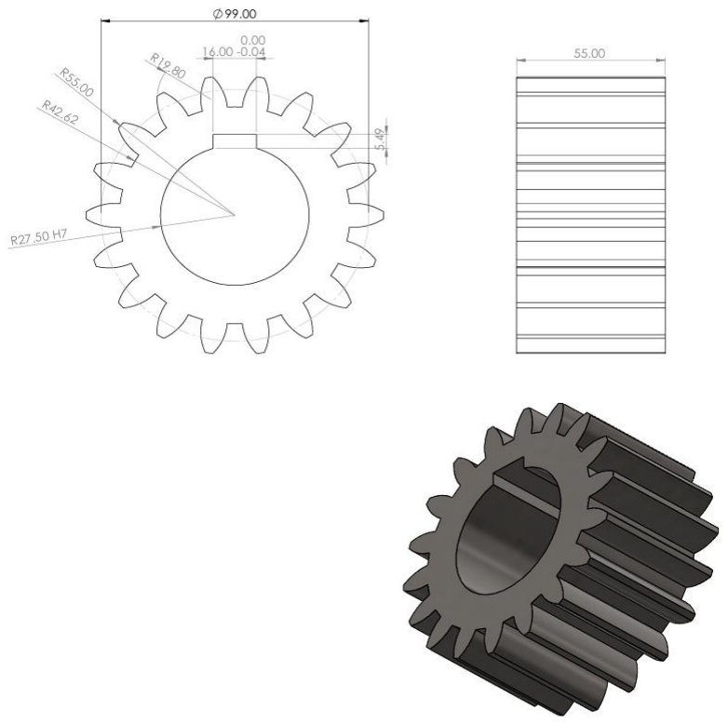
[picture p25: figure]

## 12 نقشهها

### 12 چرخدنده ی ساده Pinion

1

فصل یوازیهن: ا شهها اجرا 35

12چرخدنده ی ساده Gear

2

فصل یوازیهن: ا شهها اجرا 36


### 12 چرخدنده ی هلیكال Pinion

3

فصل یوازیهن: ا شهها اجرا 37

12چرخدنده ی هلیكال Gear

4

فصل یوازیهن: ا شهها اجرا 38


12چرخدنده ی مخروطي Pinion

5

فصل یوازیهن: ا شهها اجرا 39

12چرخدنده ی مخروطي Gear

6

12.7شافت 1 | فصل یوازیهن: ا شهها اجرا 40


فصل یوازیهن: ا شهها اجرا 41

Flange 1 (For B1)12

8

فصل یوازیهن: ا شهها اجرا 42


Flange 2 (For B2)12

9

12.10شافت 2 | فصل یوازیهن: ا شهها اجرا 43

فصل یوازیهن: ا شهها اجرا 44


Flange

s

3&4 (For B3 & B4

)12

.11

12.12شافت 3 | فصل یوازیهن: ا شهها اجرا 45

فصل یوازیهن: ا شهها اجرا 46

12.13هوسینگ برای رولربیرينگهای شافت 3 (Housing(


فصل یوازیهن: ا شهها اجرا 47

12پوسته گیربكس (Case(

.14

12.15 در پوسته گیربكس )Door Case ) | فصل یوازیهن: ا شهها اجرا 48


فصل یوازیهن: ا شهها اجرا 49

### 12 نقشه مقطع گیربكس

.16

فصل یوازیهن: ا شهها اجرا 50


Exploded View 12

.17

فصل هشتن: ا شهها اجرا 51

Bill of Material 12.18

Column1 | Column2
1 Shaft 1
2 Shaft 2
3 Shaft 3
4 Case
5 Case Door
6 Helical Gear Mo.5 D.92.4 7 Helical Gear Mo.5 D.272
8 Straight Bevel Gears Mo.6 D.168 9 Straight Bevel Gears Mo.6 D.414 10 Deep Grove Ball Bearing 6408 11 Tapper Roller Bearing 32011X/Q 12 Tapper Roller Bearing 330177/Q 13 Flange 1 (Bearing 1)
14 Flange 2 (Bearing 2)
15 Flange 3 (Bearing 3)
16 Flange 4 (Bearing 4)
17 Housing (5, 6)
18 6*M14*2 Screw Machine
19 6*M16*2 Screw Machine
20 6*M12*1.75 Screw Machine 21 6*M12*1.75 Screw Machine 22 6*M16*2 Screw Machine
23 18*M10*1.5 Screw Machine 24 Circlip DIN 471 - 35*1.5 25 Circlip DIN 471 - 40*1.75 26 Circlip DIN 471 - 55*2
27 Circlip DIN 472 - 62*2
28 Circlip DIN 472 - 50*2
29 Circlip DIN 471 - 85*3
30 Circlip DIN 471 - 70*2.5

فصل یيریهن: مواتاژ 52

## 13 مونتاژ

13.1نحوه مونتاژ

اجرایی به باید مواتاژ شواد علا)تند از: پویته بيربكب، ی) بيربكب، شافت،1 شافت،2 شافت،3 پولی،2 چرخداده هليكاد،1 چرخداده هليكاد ،2 چرخداده مخروطی،3 چرخداده مخروطی،4 چرخ زاجير، یو عدی بللرینگ ،6408 یو عدی )ولربيرینگ 32011 Face-to-Face، یو عدی )ولربيرینگ 33017 به صو)گ Back -to-Back، فلنجها 1و2و 3و،4 یه عدی بایه ازد، هاویينگ، پيچ ها، خا) و خا) فنر ها. ابتدا 1B( ا )و شافت1 اصا می بنين و شافت )ا ی) پویته بيربكب قرا) می یهين، یپب 2B
)ا از یزت ییگر شافت، )و آن اصا می بنين. خا) 1G( ا )و شافت قرا) یایه و بعد از آن، چرخداده )و شافت یوا) می شوی. خا) فنر ها )ا از یوطرف وا)ی می بنين تا پشت بللرینگ ها )ا بگيراد. بعد، فلنجها 1و2 )ا ی) محل مشخ شده )و پویته پيچ میبنين. حاال 2P( ا اير اصا می بنين.

ی) این مرحله به یراغ شافت 2 )فته و ابتدا 3B( ا از یزت چپ )و شافت اصا می بنين.
یپب، 4B از یزت ییگر پشت پله اصا می شوی. با بعد از اصا خا)، اتصاد چرخدادههایت به برا اینبا) اود 2G ی) محل مربوطه اصا و بعد فلنج مربوط به 4B از یزت )ایت اصا میشوی. حاال 4G )ا از یزت )ایت ی) محل مربوطه بين جا خا)فنر و پله قرا) می یهين. خا)فنر ها )ا ی) جا خوی قرا) یایه و یپب فلنج 3B( ا از یزت چپ ی) پویته پيچ می بنين.

قلل از اصا شافت3 )و پویته بيربكب، ابتدا یو )ولربرینگ 5و 6 از یوطرف )و شافت3 قرا)
یایه می شواد. یپب 4G بعد از قرا)بير خا) مربوطه، اصا می شوی. یو)اخ ایجای شده )و پویته ی) این قمزت بزی از قطر 4G بر)بتر ایت تا خوایته یواد برآو)یه شوی رتا یاده 4G بتوااد از بشویبی بيربكب بيرون بيایدا. حاال هاویينگ )و )ولربيرینگ ها اصا شده و بل مجزوعه وا)ی پویته می شوی. بعد از آن، هاویينگ به پویته پيچ شده و خا)فنر ها و 5G( و شافت3 اصا می شواد. ی) آخر هن بعد از اصا ی) پویته، بایه ازد ها تهيه شده )و فلنج ها 1 و 3 و بيرون هاویينگ
قرا) می بيراد.

فصل یيریهن: مواتاژ 53

13.2تثبیت محوری و دوراني قطعات

شافت 1

تثليت ها یو)اای:
2P: با ایتفایه از یک خا) ممتطيلی mm8 × mm10 به طود 55 ميلی متر تثليت یو)اای می شوی. 1G: با ایتفایه از یک خا) ممتطيلی mm10 × mm16 به طود 44 ميلی متر تثليت یو)اای می شوی.

تثليت ها محو) :
2P: پشت آن تویط خا)فنر 35 DSH مها) شده و جلو آن هن پله قرا) یا)ی. 1G: ی) پشت آن پله و ی) جلو آن خا)فنر 54 DSH قرا) یایه شده ایت. 1B: ی) شافت 1 یو بللرینگ یایه ایتفایه شده به 1B( ا Locating ی) اظربرفتين. بنابراین، بنب یاخلی آن از جلو با پله و از پشت با خا)فنر 40 DSH تثليت محو) شدهایت. به عالوه، بنب خا)جی آن هن از پشت با فلنج و از جلو با مااعی به ی) پویته بيربكب طراحی شده، مها) شده ایت. 2B: این بللرینگ به صو)گ locating-Non طراحی شده، به این حالت به بنب یاخلی از جلو با خا)فنر 40 DSH و از پشت با پله مها) شده و بنب خا)جی آن از یوطرف آزای ایت.

شافت 2

تثليت ها یو)اای:
2G: با ایتفایه از یک خا) ممتطيلی mm11 × mm18 به طود 43 ميلی متر تثليت یو)اای می شوی. 3G: با ایتفایه از یک خا) ممتطيلی mm9 × mm14 به طود 44 ميلی متر تثليت یو)اای می شوی.

تثليت ها محو) :
2G: پشت آن تویط خا)فنر 62 DSH مها) شده و جلو آن هن پله قرا) یا)ی. 3G: ی) پشت آن پله و ی) جلو آن خا)فنر 50 DSH قرا) یایه شده ایت.

فصل یيریهن: مواتاژ 54

4B & 3B: ی) شافت ،2 یو عدی )ولربرینگ مخروطی به صو)گ Face-to-Face ایتفایه شده ایت. پشت بنب خا)جی 3B و جلو بنب خا)جی 4B با فلنج ها مربوطه مها) شداد. به عالوه، جلو بنب یاخلی 3B و پشت بنب یاخلی 4B با پله ها مجاو)شان امكان حربت محو) ادا)اد.

شافت 3

تثليت ها یو)اای:
4G: با ایتفایه از یک خا) ممتطيلی mm12 × mm20 به طود 90 ميلی متر تثليت یو)اای می شوی.

5G: با ایتفایه از یک خا) ممتطيلی mm12 × mm20 به طود 90 ميلی متر تثليت یو)اای می شوی.

تثليت ها محو) :
4G: پشت آن تویط خا)فنر 70 DSH مها) شده و جلو آن هن پله قرا) یا)ی به 4G با ایتفایه از اافی متصل شده به آن، به پله می )ید . 5G: ی) پشت آن پله و ی) جلو آن خا)فنر 70 DSH قرا) یایه شده ایت.

6B & 5B: ی) شافت ،3 یو عدی )ولربرینگ مخروطی به صو)گ Back-to-Back ایتفایه شده ایت. جلو بنب خا)جی 5B و پشت بنب خا)جی 6B با فلنج ها مربوطه مها) شداد. به عالوه، ی) پشت بنب یاخلی 5B و جلو بنب یاخلی 6B با ایتفایه از خا)فنر ها 85 DSH امكان حربت محو) ادا)اد.

فصل چها)یهن: برآو)ی قيزت 55

## 14 برآورد قیمت

الز به بر ایت به به یليل قطعی اینترات ی) ) وز ها پنجشنله، جزعه و شنله امكان تكزيل این قمزت وجوی اداشت. اما ليمت قطعاگ ی) صفح ه 51 موجوی ایت.

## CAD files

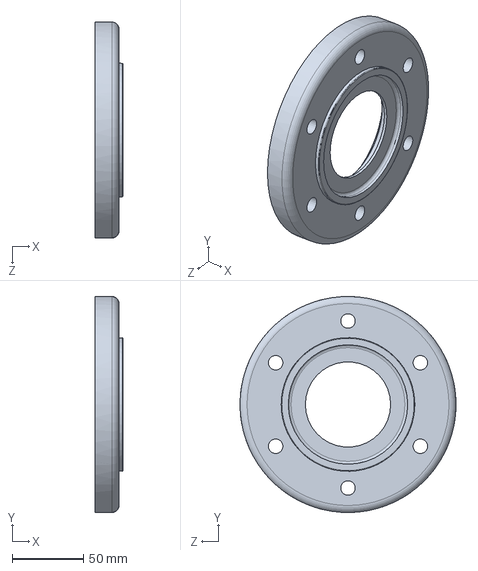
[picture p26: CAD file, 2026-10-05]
solidworks/Flange 3.SLDPRT
19.9 x 152.0 x 152.0 mm

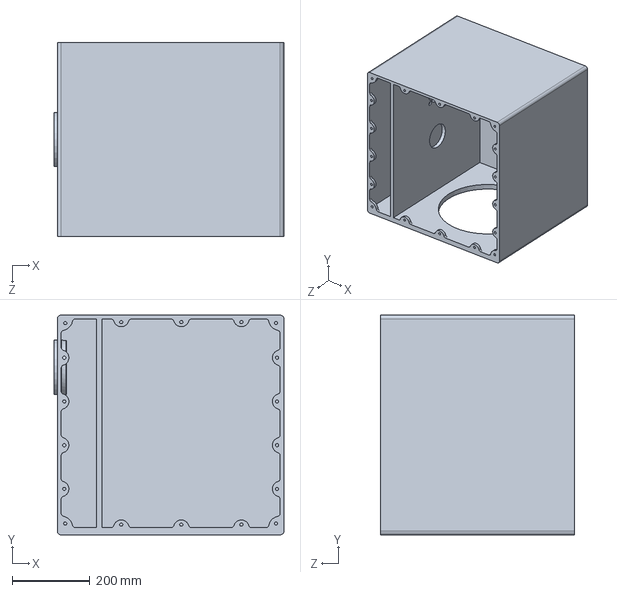
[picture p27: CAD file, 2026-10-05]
solidworks/Part2.SLDPRT
593.5 x 567.2 x 500.0 mm

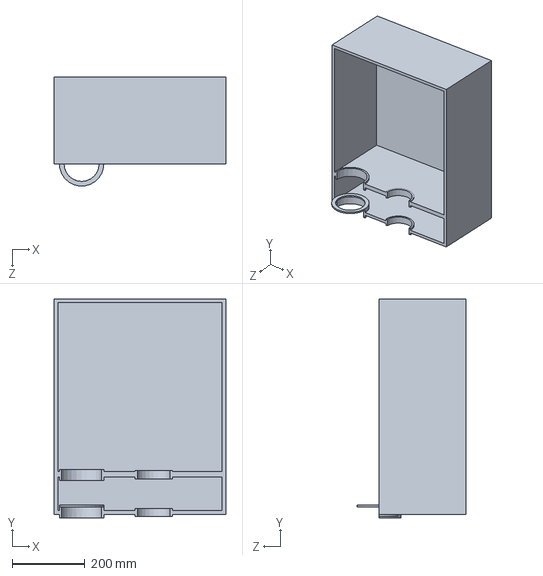
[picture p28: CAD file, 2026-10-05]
solidworks/Case.SLDPRT
470.0 x 600.0 x 298.5 mm

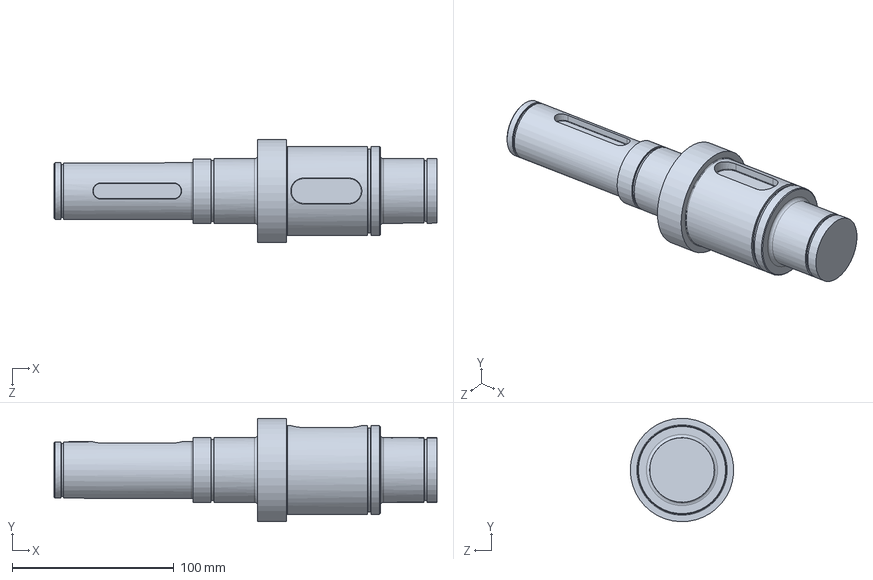
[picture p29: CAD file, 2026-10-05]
solidworks/Shaft1.SLDPRT
237.0 x 64.0 x 64.0 mm

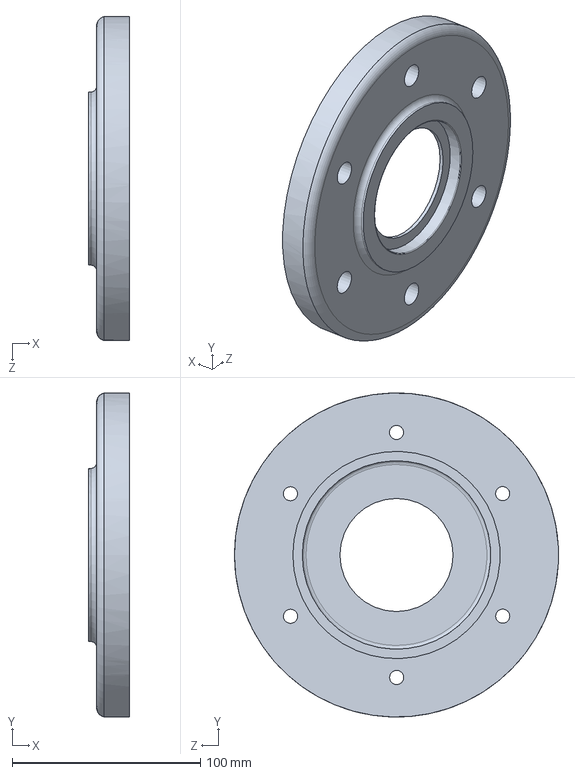
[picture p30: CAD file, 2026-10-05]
solidworks/Flange 1.SLDPRT
21.5 x 172.0 x 172.0 mm

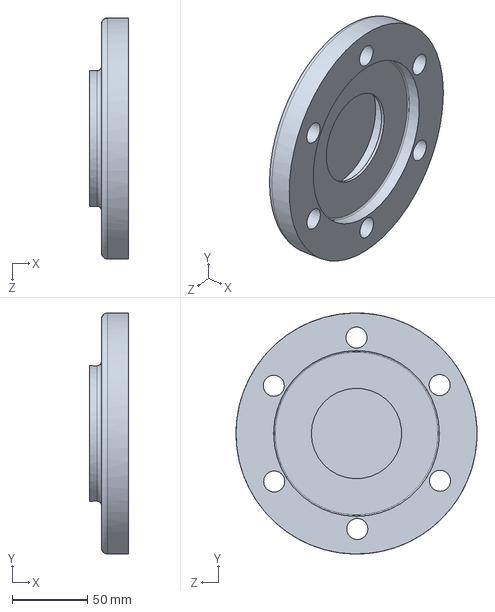
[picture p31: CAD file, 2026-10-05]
solidworks/Flange 2.SLDPRT
25.9 x 160.0 x 160.0 mm

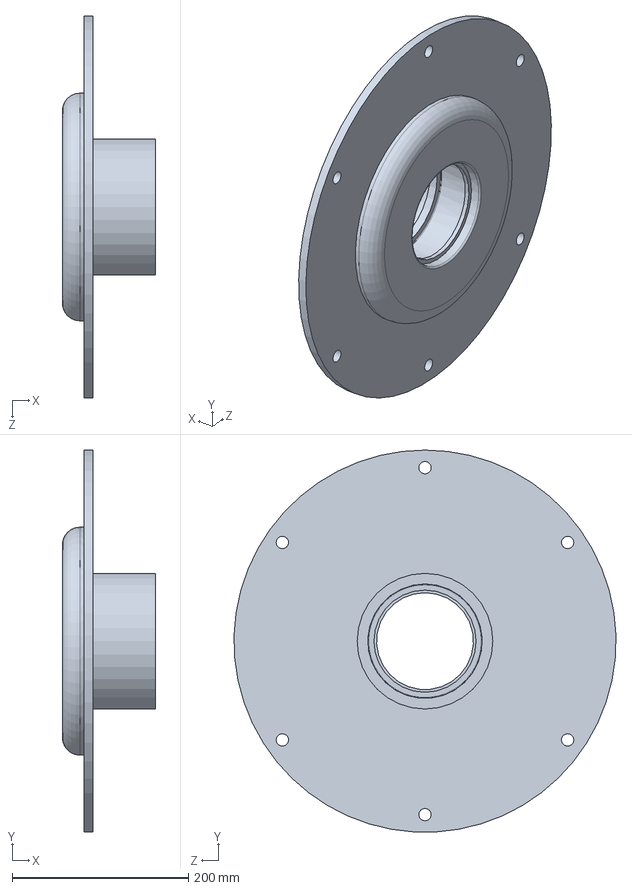
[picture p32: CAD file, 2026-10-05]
solidworks/Housing.SLDPRT
106.0 x 433.6 x 433.8 mm

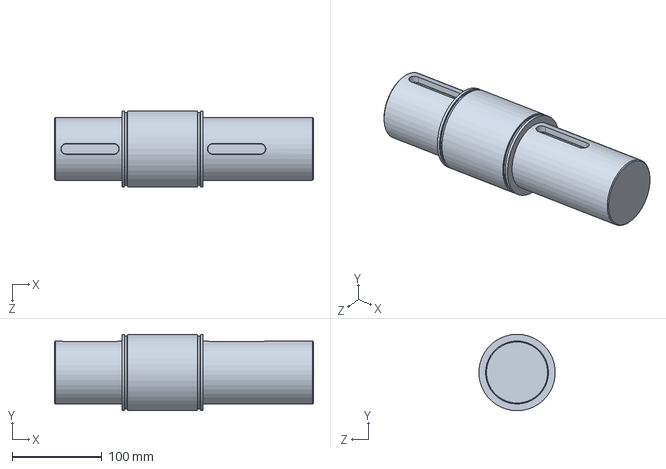
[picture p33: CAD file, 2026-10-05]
solidworks/Shaft3.SLDPRT
288.0 x 85.0 x 84.9 mm

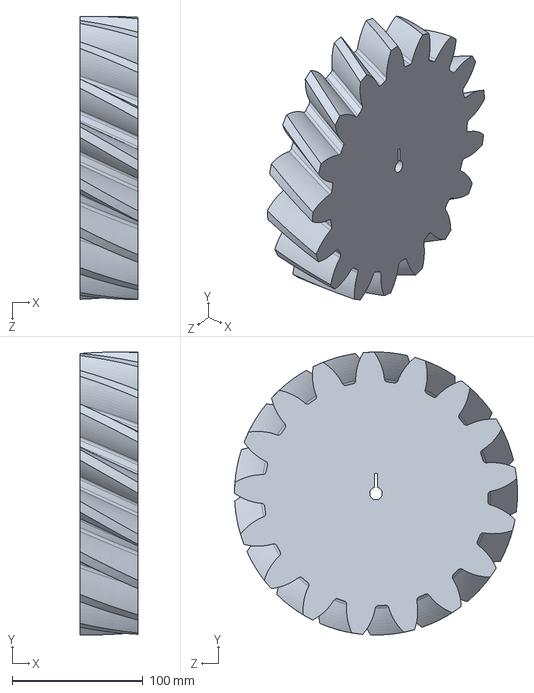
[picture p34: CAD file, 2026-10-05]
solidworks/Heli3.SLDPRT
44.5 x 216.3 x 216.3 mm

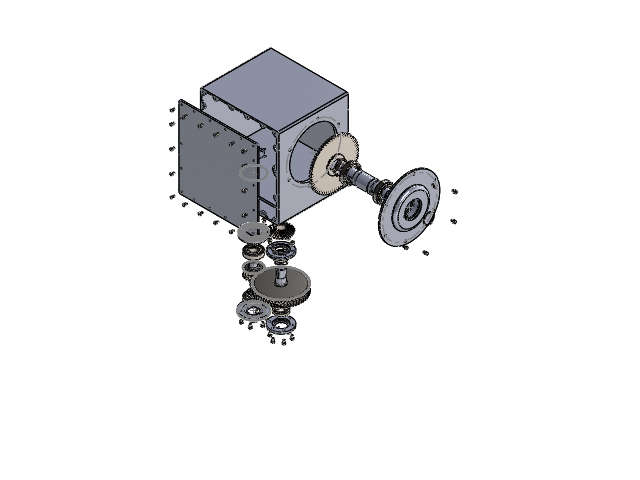
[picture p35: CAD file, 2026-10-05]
solidworks/GearBox.SLDASM
Housing
Shaft1
Shaft2
Shaft3
radial ball bearing_68_skf x 2
taper roller bearing_skf x 4
Flange 1
Flange 2
Flange 3
helical gear_3_am x 2
straight bevel gear_iso x 2
Part1^GearBox
CaseDoor
circlip for shafts normal_din x 8
Part2^GearBox
Flange 3new
circlip for bores normal_din x 2
hex screw_am x 48

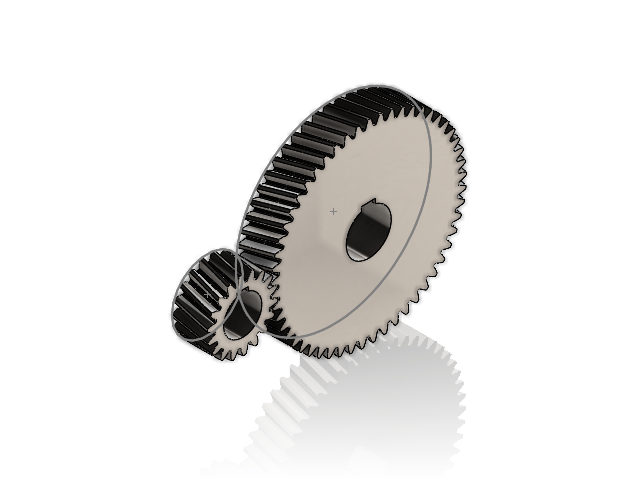
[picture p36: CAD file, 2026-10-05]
solidworks/AssemHeli.SLDASM
helical gear_3_am x 2

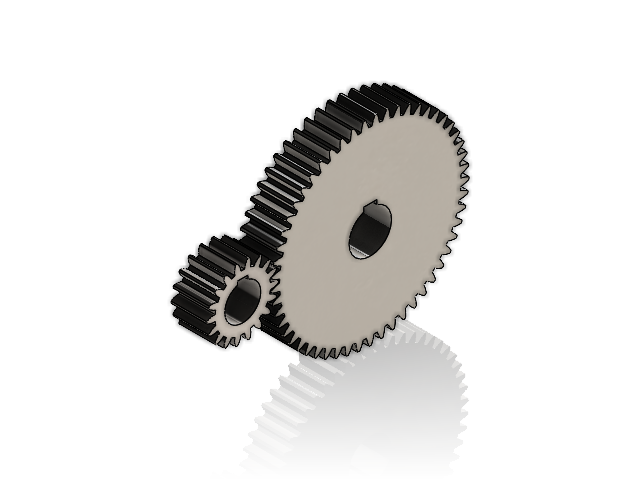
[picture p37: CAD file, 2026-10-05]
solidworks/AssemSpur.SLDASM
spur gear_am x 2

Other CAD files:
solidworks/G1Spur.SLDASM
solidworks/Heli2.SLDASM
solidworks/Heli1.SLDASM
solidworks/G2Spur.SLDASM
solidworks/Part1.SLDPRT
solidworks/CaseDoor.SLDPRT
solidworks/Case.SLDDRW
solidworks/CaseDoor.SLDDRW
solidworks/Flange 1.SLDDRW
solidworks/Flange 2.SLDDRW
solidworks/Flange 3.SLDDRW
solidworks/G1Spur.SLDDRW
solidworks/G2Spur.SLDDRW
solidworks/GearBox Exploded.SLDDRW
solidworks/Housing.SLDDRW
solidworks/SECTION-2.SLDDRW
solidworks/SECTION.SLDDRW
solidworks/Shaft1.SLDDRW
solidworks/Shaft2.SLDDRW
solidworks/Shaft2.SLDPRT
solidworks/Shaft3.SLDDRW
